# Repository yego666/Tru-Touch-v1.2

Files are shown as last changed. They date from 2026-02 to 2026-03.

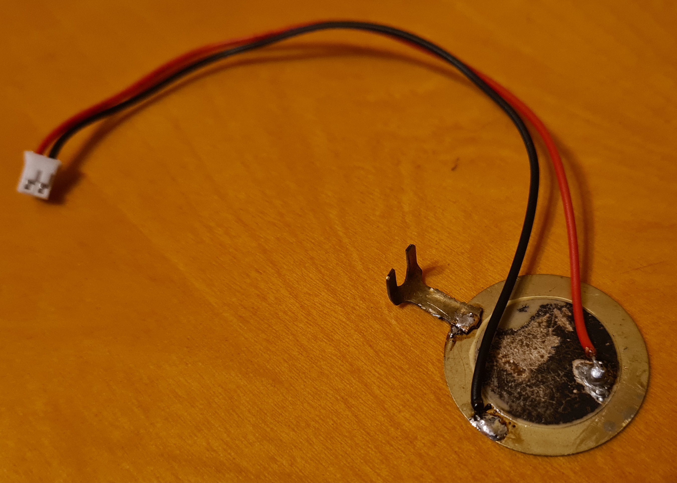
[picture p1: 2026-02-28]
docs/assets/wiring/piezo_sensor.jpg

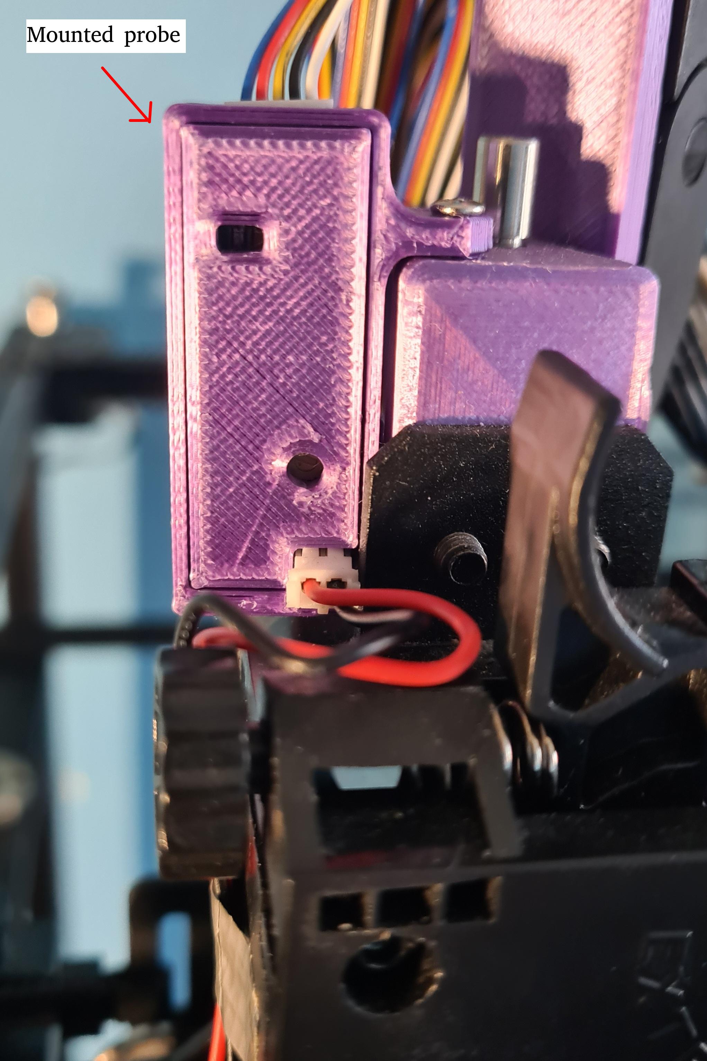
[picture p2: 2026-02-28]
docs/assets/images/mounted-probe.jpg

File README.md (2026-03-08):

# Tru-Touch v1.2 – 1.5-Micron Precision Nozzle-Contact Probe for 3D Printers

# 🚀 Tru-Touch v1.2: High-Precision Nozzle Probe

**Tru-Touch v1.2** is an intelligent, piezoelectric nozzle-contact probe designed for 3D printers.  
It achieves sub-micron precision by using the **nozzle itself** as the trigger point — eliminating offset calibration.

### Key Performance Metrics


- **Precision (Repeatability)**:  1.5 Microns (0.0015 mm) verified
- **Typical Standard Deviation**: 0.001369 mm (validated in Klipper, stats provided)
- **Zero Offset on All Axes**:    Probes directly with the nozzle — no X/Y offset calibration
- **Thermal Stability**:          Controller board detached from piezo sensor
- **No Maintenance Solution**:    Install, Fine-tune, Set up, and forget.
- **Perfect for Adaptive Bed Meshing**: Works perfectly with native Klipper Adaptive Bed Meshing

### Hardware Features
- **One-Screw Mounting**: Minimalist carriage mount; adds negligible mass to the toolhead
- **Easy Installation**:  Reuses existing BL-Touch cabling with minor adjustments
- **Hybrid Processing**:  Analog preconditioning + DSP for superior noise rejection
- **Visual Feedback**:    Dual LEDs with heartbeat and real-time contact-blink patterns
- **User Tunable**:       Onboard potentiometer to match trigger threshold to your gantry resonance

Tru-Touch Probe

 ***Note*** : Battery not included.
### CRITICAL: SIMPLE PLUG RE-PINNING REQUIRED
Tru-Touch v1.2 uses a specialized safety-interlock pin-out. You **MUST** rearrange your JST/DuPont connector to match the TRU-TOUCH row before applying power.

### Repository Contents
- `README.md`: Introduction to the Tru-Touch Probe and its features
- `TruTouch_v1.2_Mechanical.step`: 3D model for designing custom mounts.
- `Physical-Installation.pdf`: Full technical specs and physical installation instructions.
- `Klipper_Integration_Guide.pdf`: Detailed Klipper integration instructions.
- `Probe_Tuning_Guide.pdf`: Step by step guide on probe tuning for best performance
- `Printing_notes.pdf`: Some notes on leveling and printing with the Tru-Touch Probe

Installation Guide: [TruTouch_v1.2_Physical-Installation.pdf](https://github.com/yego666/Tru-Touch-v1.2/blob/main/docs/guides/physical-installation.pdf))

klipper_integration_guide: [TruTouch_v1.2_klipper_integration_guide.pdf](https://github.com/yego666/Tru-Touch-v1.2/blob/main/docs/guides/klipper_integration_guide.pdf))

probe_tuning_guide: [TruTouch_v1.2_probe_tuning_guide.pdf](https://github.com/yego666/Tru-Touch-v1.2/blob/main/docs/guides/probe_tuning_guide.pdf))

printing_notes.: [TruTouch_v1.2_printing_notes.pdf](https://github.com/yego666/Tru-Touch-v1.2/blob/main/docs/guides/printing_notes.pdf))

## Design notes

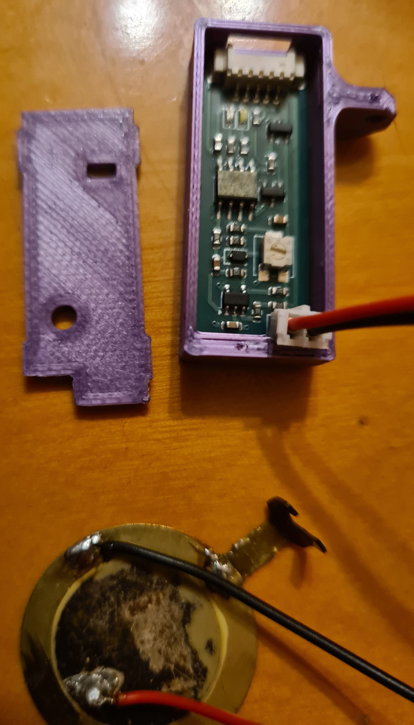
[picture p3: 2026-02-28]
docs/assets/images/trutouch-case.jpg

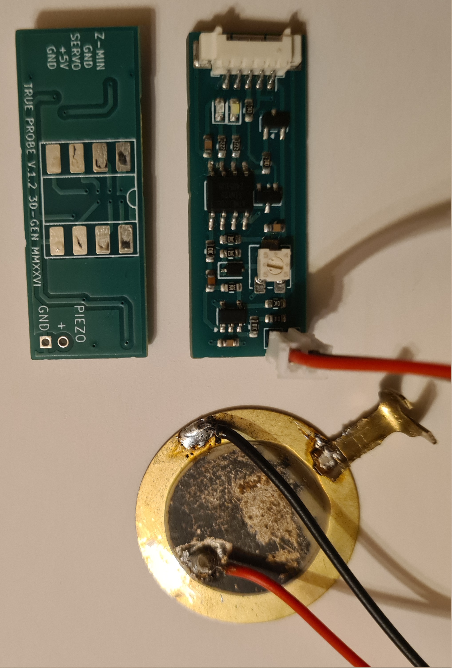
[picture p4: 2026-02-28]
docs/assets/images/trutouch_set.jpg

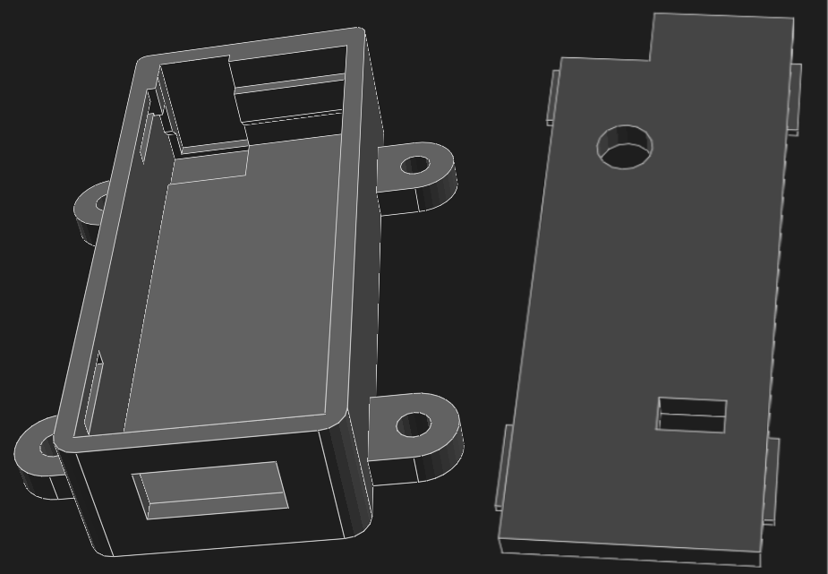
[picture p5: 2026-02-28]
docs/assets/images/trutouch_case.png

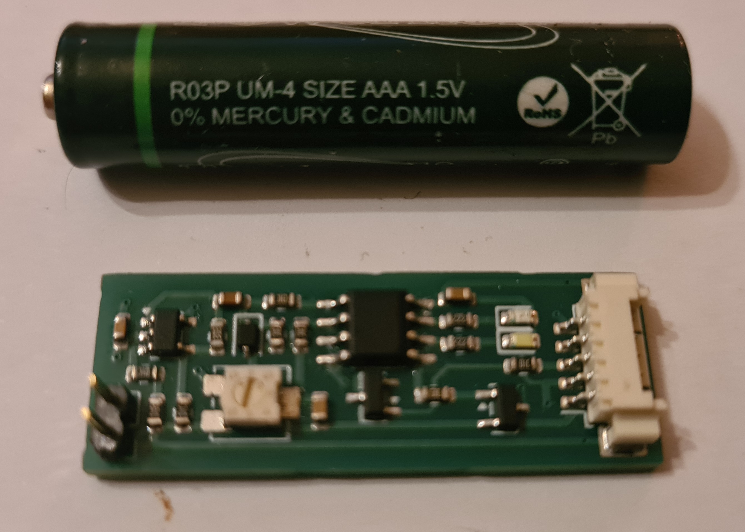
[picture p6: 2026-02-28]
docs/assets/images/trutouch_real-view.jpg

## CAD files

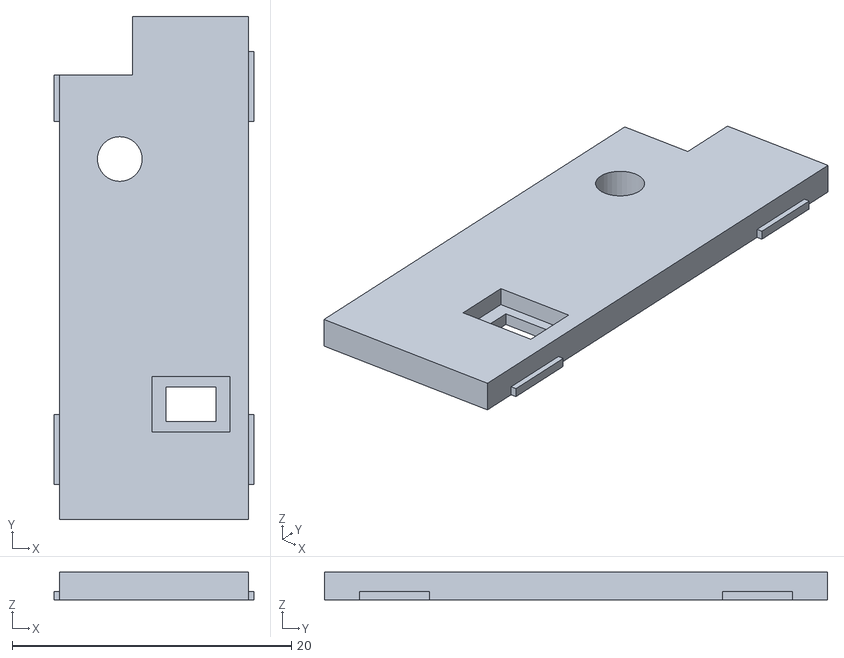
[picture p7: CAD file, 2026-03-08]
docs/stl-step/trutouch-cover.stl
14.3 x 36.0 x 2.00

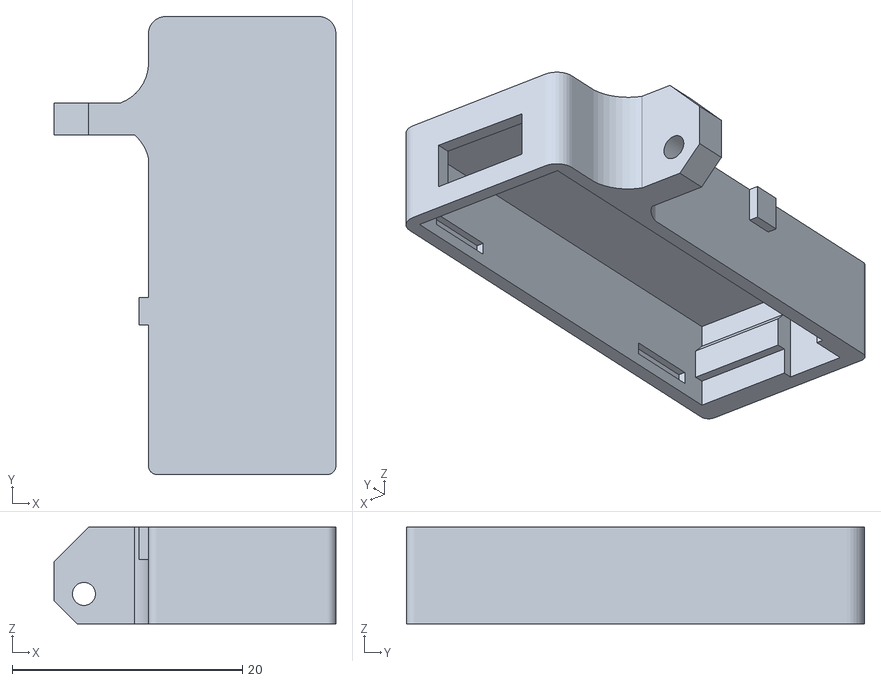
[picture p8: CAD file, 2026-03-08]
docs/stl-step/trutouch-base-2.stl
24.5 x 39.8 x 8.40

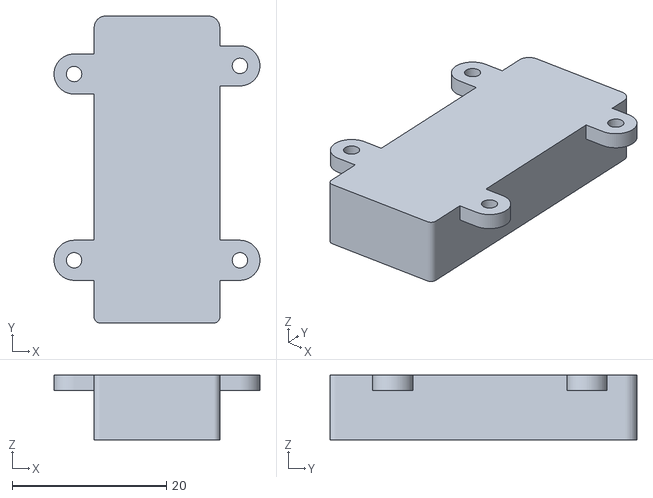
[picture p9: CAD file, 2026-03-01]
docs/stl-step/trutouch-base-1.stl
26.7 x 39.8 x 8.40

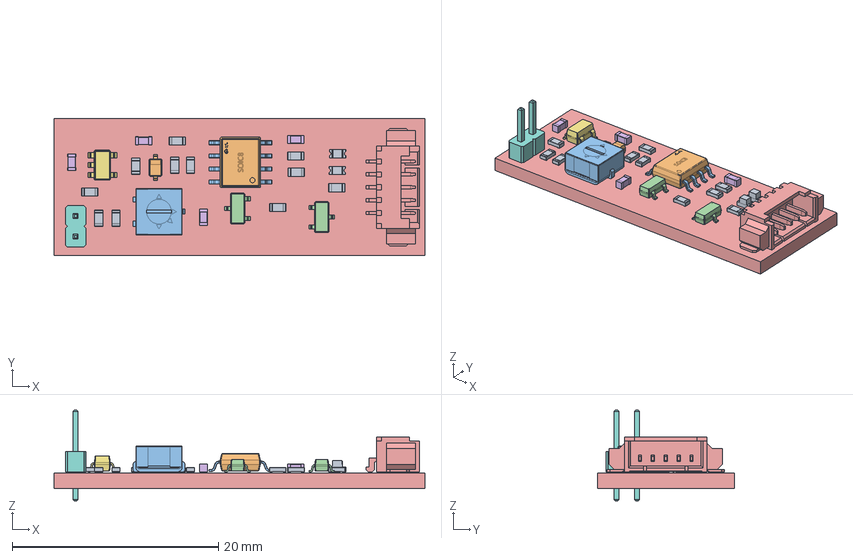
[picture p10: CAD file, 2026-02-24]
docs/stl-step/trutouch.step
35.9 x 13.3 x 8.80 mm
R_0603
D_SOD-323
R_0603_1608Metric x 10
Potentiometer_Bourns_3314J_Vertical
SOT-23 x 2
Molex_PicoBlade_53261-0571_1x05-1MP_P1.25mm_Horizontal
C_0603 x 4
SOT-23-5
PinHeader_1x02_P2.00mm_Vertical
D_0603 x 2
SOIC-8_L4.9-W3.9-P1.27-LS6.0-BL
jlcpcb_probe-v1.2_PCB

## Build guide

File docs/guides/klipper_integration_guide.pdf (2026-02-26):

Having completed all the steps in the Physical Installation Guide successfully, you can now integrate your new Tru-Touch piezo probe into your Klipper configuration so you can start using it. Basic (and most crucial) configuration takes place in the printer.cfg file, where all hardware features must be clearly specified.
With proper (re-)wiring, the two most important signals are covered: Z-MIN feedback signal, and the SERVO probe control signal.

# Configuration Options: BLTouch Mode vs. Simple Probe Mode

Tru-Touch may be configured either as a direct BLTouch/CR-Touch replacement from the signaling perspective, or as a probe with the simple ON/OFF control signal.
Depending on the way it is configured in the printer.cfg file, the probe will automatically switch to the chosen mode.
Both modes have their pros and cons.
Choosing the BLTouch compatible mode you are bound to tight PWM timing/control signals, which may be misinterpreted in some printers due to noise, timing jitter, or board-specific quirks. This could cause misinterpretation of deploy/stow commands, potentially leading to bed crashes, false triggers, or no triggers at all.

# The Tru-Touch probe emulates only the basic BLTouch commands, as the Touch Mode Fast

scanning mode cannot be safely implemented with piezo sensors.
However, BLTouch mode allows for an almost plug-and-play configuration if you already have a BLTouch defined in printer.cfg.
The Simple Probe Mode offers a very simple and straightforward configuration, while giving you full control over probing speed and various other probing parameters.
It uses the same wiring and control signals as the BLTouch mode, so no printer board rewiring is required. BLTouch probe control signals may be safely reused.
This mode is also slightly faster than the BLTouch mode as Klipper must take care of just ON and OFF states instead of handling more complicated PWM control signal sequences.
The following sections explain both modes in detail, including recommended printer.cfg entries and tuning tips for optimal piezo performance.

BLTouch Mode

[bltouch]

sensor_pin: your sensor (Z-MIN) pin designator | # for instance PF12
control_pin: your control (servo) pin designator | # for instance PB10
pin_move_time: 0.020 | # must be set low to avoid conflict with Tru-Touch timing
stow_on_each_sample: True | # must be set True for proper Tru-Touch operation
probe_with_touch_mode: False | # no Touch Mode is available
x_offset: 0 | # this offset must be set to “0” as the nozzle is your probe
y_offset: 0 | # this offset must be set to “0” as the nozzle is your probe
z_offset: 0 | # this offset must be set to “0” as the nozzle is your probe
speed: 6.7 | # adjust within safe limits [5, 7] mm/s

lift_speed: 30

sample_retract_dist: 4 | # set it the same as the [stepper_z]:homing_retract_dist
#samples: 3 | # the number of samples to take at the same x/y spot

#samples_result: median | # samples beyond the samples_tolerance will be discarded

#samples_tolerance: 0.010 | #samples_tolerance_retries: 3

Simple Probe Mode:

[probe]

pin: your sensor (Z-MIN) pin designator | # for instance PF12
x_offset: 0 | # this offset must be set to “0” as the nozzle is your probe
y_offset: 0 | # this offset must be set to “0” as the nozzle is your probe
z_offset: 0 | # this offset must be set to “0” as the nozzle is your probe
speed: 6.7 | # adjust within safe limits [5, 7] mm/s
sample_retract_dist: 4 | # set it equal to [stepper_z]:homing_retract_dist
#samples: 3 | # the number of samples to take at the same x/y spot

#samples_result: median | # samples beyond the samples_tolerance will be discarded

#samples_tolerance: 0.010

#samples_tolerance_retries: 3

activate_gcode:

PROBE_ON

deactivate_gcode:

PROBE_OFF

#--------- Control Pin Macro for the Simple Probe Mode ----------

[output_pin servo_pin]

pin: your control (servo) pin designator | # for instance PB10

pwm: False

value: 0

[gcode_macro PROBE_DEPLOY]

gcode:

SET_PIN PIN=servo_pin VALUE=0

[gcode_macro PROBE_STOW]

gcode:

SET_PIN PIN=servo_pin VALUE=1

Settings common to both modes:

[stepper_z]

position_min: -1.0 | # too low value may cause no trigger error,

# due to motion planner limitations

homing_speed: 6.7

homing_retract_dist: 4 | # Distance to back off after first and second homing
second_homing_speed: 6.7 | # should be given the same value as the homing_speed

[safe_z_home]

z_hop: 4 | # Distance (in mm) to lower the bed prior to first homing.

# Best to set it the same as the [stepper_z]:homing_retract_dist

[bed_mesh]

horizontal_move_z: 4 | # The height (in mm) that the bed should move to,
| # just prior to starting a mesh probe operation.
| # Set it the same as the [stepper_z]:homing_retract_dist
#-⁻ | Extra macros needed for easy Tru-Touch probe setup for both modes -⁻

# Use the UNLOCK_Z macro to move the bed up or down if G28 fails to home the Z AXIS

[force_move] | # This block is required by the SET_KINEMATIC_POSITION
| # commands in the UNLOCK_Z macro below

enable_force_move: True

[gcode_macro UNLOCK_Z]

gcode: SET_KINEMATIC_POSITION Z=100

Note: Only parameters directly impacting the Tru-Touch probe’s operation have been displayed above. Other parameters may be left unmodified as they were before if they don’t collide with settings discussed above.
If the parameter “z_offset” is present in the SAVE_CONFIG section, remove it as it will override, thus invalidate your “0” offset settings.

# The [bltouch] and the [probe] sections cannot be defined at the same time within the same

printer.cfg file, as that will cause configuration conflict.

Whichever mode you choose, you may switch to the other at any time, as once properly (re-)wired, your probe is electrically identical for both modes, hence the same pins are used in both cases.

Hence the power up sequence has been covered in the installation Guide, we may proceed to the Probe Tuning Guide.

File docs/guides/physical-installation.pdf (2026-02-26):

## Tru-Touch v1.2 Wiring Diagram – 1.25 mm Picoblade Connector CRITICAL SAFETY WARNING – READ BEFORE CONNECTING POWER

Re-pin the printer-side female plug to match the colors and functions shown below. Incorrect wiring order WILL DAMAGE the probe and/or printer electronics.

Always verify with a multimeter before first power-up.

Two GND wires (red and white) — connect both to the printer board’s GND (signal & power noise reduction).

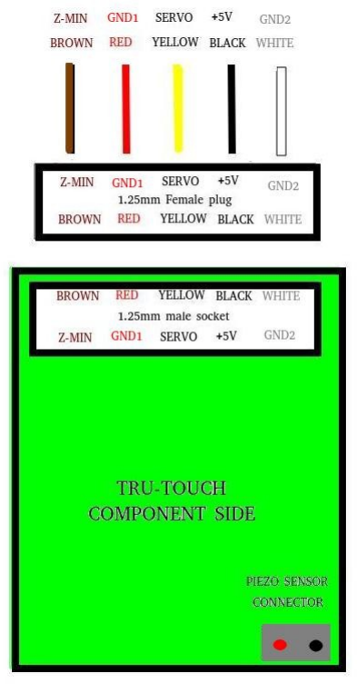
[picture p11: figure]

## Viewed from Component Side & Quick Reference – Wire Matching

(green PCB facing you, with the connector also on the component side).

⁻ | Brown | → | Z-MIN (probe trigger output to Klipper sensor_pin)
⁻ | Red | → | GND1
⁻ | Yellow | → | SERVO (PWM command from Klipper)
⁻ | Black | → | +5V (power from printer)
⁻ | White | → | GND2

## Piezo Sensor

The piezo sensor is a small disc with a diameter of roughly 30 mm.

It consists of a brass base (yellow, metallic part) and a piezo-ceramic sensor located centrally on the brass base.

There are two wires soldered to the component.

The red one is soldered to the piezo-ceramic disc, while the black one is soldered to the brass rim. Those wires are crimped into the 2 mm female plug, which should be plugged into the Piezo Sensor Connector on your Probe as discussed below.

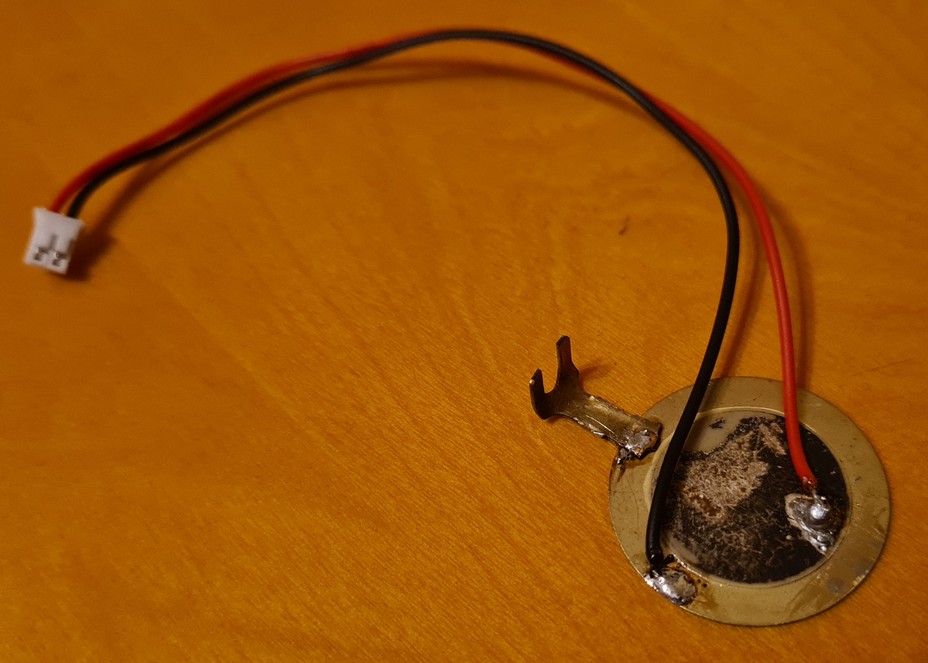
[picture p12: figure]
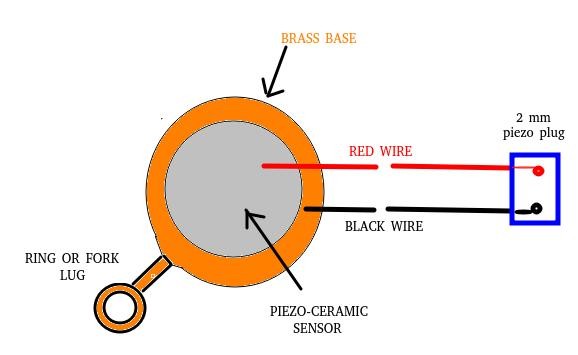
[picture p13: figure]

You can see the Fork Lug (left picture), and the Ring Lug (right picture) soldered to the brass rim of the disc. This lug is used to attach the whole piezo assembly to your printer’s carriage.

It must be attached with a suitable screw to allow it to receive the vibrations from the nozzle tapping against your printer’s bed.

## Best place to attach your piezo assembly:

1. The piezo disc must be fixed parallel to the printer’s bed.
2. It must be attached to the same back-plate that the hot-end is attached to,
3. For best performance it should be not closer to the bed than 45 – 50 mm,
4. It must be attached firmly to let the vibration easily pass from the nozzle.

## Piezo Sensor Connector (bottom right on PCB)

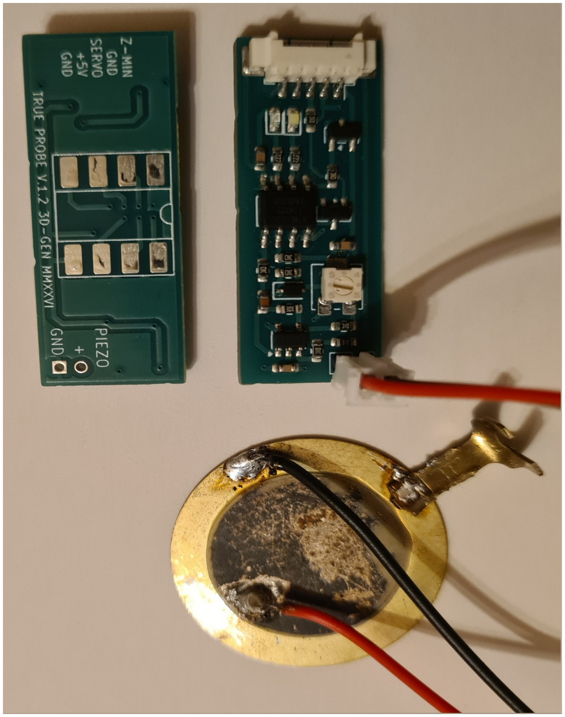
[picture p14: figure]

Connect the piezo disc:

red wire to the marked (+) pin,

black wire to the marked (GND) pin.
Polarity matters: The brass part of the piezo disc connects to the printer’s ground via the frame.

Note: Ensure the nozzle and the bed are clean and debris-free for reliable performance.

## First Power-Up Check

After wiring:

1. Power on the printer → the RED LED and the WHITE LED should blink quickly several times (self-test state), and eventually rest with the RED LED OFF and the WHITE LED dimmed.
2. Send the “BLTOUCH_DEBUG COMMAND=pin_down” → the heartbeat LED (white) dims, then turns ON.
3. Manually trigger piezo → the contact LED (red) turns on, and remains triggered (ON) until the “BLTOUCH_DEBUG COMMAND=pin_up” is received.

If no LEDs light up or if there is wrong behavior → re-check the wiring & re-pin the connector.

When all steps have been passed successfully, you may proceed to the Klipper Integration Guide.

## Tools needed:

Multimeter, small flat or philips screwdriver, caliper for verification, sharp needle or a pin for signal connector re-pinning.

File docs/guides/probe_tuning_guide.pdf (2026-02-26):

### Probe Tuning Guide

Assuming that your printer is connected to the controlling computer, and Klipper is configured according to the guidelines in the Klipper Integration Guide, you should be able to command your printer via your favorite interface.

First of all — for your printer’s safety — turn off the printer and manually move your bed away from the nozzle to give it some slack to move toward the bed without hitting it. A 100 mm distance is recommended for a large error margin.

Now you may turn your printer back on and wait for it to boot up completely so you can access the Klipper console from your computer.

First, we need to set the rough sensitivity threshold for the probe.
Important note: The potentiometer is rather tiny, so changes to the probe’s sensitivity must be executed with a tiny flat screwdriver using just minute adjustments, as less precise adjustments may cause huge sensitivity changes.

### BLTouch Mode

Run the BLTOUCH_DEBUG COMMAND=pin_down. This command activates your probe — analogous to the Deploy command in a classic BLTouch probe.

The LED pattern on the probe will change as follows: RED LED turns OFF, White LED turns OFF for half a second and then turns ON, signaling the deployment sequence is complete.

[1C] Now the probe is awaiting the tap on the nozzle.

Take a screwdriver or even a steel spoon and very gently tap the bottom of the nozzle.

If the RED LED remains dim after the tap, turn the potentiometer located on the probe's PCB counterclockwise very slightly to increase the piezo sensor sensitivity, and repeat the procedure from point [1C] until the RED LED lights up.

If the RED LED lights up, send the BLTOUCH_DEBUG COMMAND=pin_up command to the printer.

The probe should return to idle state, reporting its state with the RED LED off and the WHITE LED dim.

### Simple Probe Mode

Run the PROBE_DEPLOY macro. This command activates your probe.

The LED pattern on the probe will change as follows: RED LED turns OFF, White LED turns OFF for half a second and then turns ON, signaling the deployment sequence is complete.

[1T] Now the probe is awaiting the tap on the nozzle.

Take a screwdriver or even a steel spoon and very gently tap the bottom of the nozzle.

If the RED LED remains dim after the tap, turn the potentiometer located on the probe's PCB counterclockwise very slightly to increase the piezo sensor sensitivity, and repeat the procedure from [1T] until the RED LED lights up.

If the RED LED lights up, run the PROBE_STOW macro.

The probe should return to idle state, reporting its state with the RED LED off and the WHITE LED dim.

### Common

Now the probe knows roughly the trip point.

To fine-tune this trip point, run the UNLOCK_Z macro, which will let you move your printhead over all axes.

Move your printhead to the center of your printer’s bed with the G0 X100 Y100 F5000 command (or similar depending on your bed size). This spot is usually the most suitable place to fine-tune your probe.

Once the printhead is above the bed center:

### BLTouch Mode

[2B] Run the BLTOUCH_DEBUG COMMAND=pin_down command.

Move the bed closer to the nozzle with the G0 Z90 F402 command (speed: 6.7 mm/s * 60 = 402 mm/min), while watching the RED LED on the Tru-Touch probe.

If it lights up, the sensor is too sensitive, so turn the potentiometer very slightly clockwise to lower this sensitivity. Next, run the BLTOUCH_DEBUG COMMAND=pin_up command to stow the probe, move the bed back to its initial position with the G0 Z100 F402 command, and return to step [2B].

### Simple Probe Mode

[2S] Run the PROBE_DEPLOY macro.

Move the bed closer to the nozzle with the G0 Z90 F402 command (speed: 6.7 mm/s * 60 = 402 mm/min), while watching the RED LED on the Tru-Touch probe.

If it lights up, the sensor is too sensitive, so turn the potentiometer very slightly clockwise to lower this sensitivity. Next, run the PROBE_STOW macro to stow the probe, move the bed back to its initial position with the G0 Z100 F402 command, and return to step [2S].

### Common

If the RED LED stays off, the sensor’s sensitivity may be close to optimal.

To make sure that your tuning is correct, you may rerun the tuning procedure several times.

Once you are done with fine-tuning your probe, the real HOME cycle must be done.

While your bed is still well away from the nozzle, grab the screwdriver or a spoon or whatever hard tool you used to tap the nozzle and run the G28 command to home all three axes of your printer.

First your printer will home the X and Y axes. Next it will go to the spot marked [safe_z_home]:home_xy_position: 156,156.

Once this spot is reached, the probe will deploy (watch LEDs), and the probing cycle will begin.

After the bed has traveled half the distance to the nozzle (or vice versa), gently tap the nozzle with a tool at hand. The second homing cycle will start. Again tap gently the nozzle to end the cycle. If the probe failed to detect your taps, turn off your printer to avoid any damage. In this case, the tuning procedure must be carried on again with greater care.

If, however, the probe detected your gentle taps, you may re-run the G28 command without tapping the nozzle before it reached the bed. Nevertheless, be prepared to cut your printer’s power in case the probe failed to detect the tap. In such unlikely case, the tuning procedure must be carried on again with greater care.

When your printer has been homed successfully, you should run the first surface scan (leveling) to fine-fine tune your probe.

The scan boundaries are defined in the printer.cfg file as [bed_mesh]:mesh_min: 30,30, and [bed_mesh]:mesh_max: 282,282.

Note that your bed may be much noisier on its outer rim, therefore use conservative boundaries for your first surface scan.

Later on those boundaries may be extended to your whole bed area.

### Bed Leveling

[3L] Run the BED_MESH_CALIBRATE command from your console. Best start with [bed_mesh]:probe_count: 3,3 to save time in case of failure.

If at any mesh point your probe triggers prematurely, you’ll need to slightly lower the probe’s sensitivity and start over at point [3L].

If, however, the probe missed the tap, the sensitivity must be increased slightly with the potentiometer. Rerun the Bed Leveling procedure from [3L] once you trimmed the sensitivity. Note: Missed tap may also result from the nozzle or bed not being clean enough.

Once the leveling was successful, you may rerun it with [bed_mesh]:probe_count: set to your desired values.

Note !!!: The potentiometer is not your only tool to fight over or under sensitivity.

In unlikely case where you get both premature triggers and missed taps, you may tune the noise with the “speed” parameters both in [bltouch] or [probe] sections, and [stepper_z] section.

While changing the “speed” parameter value keep in mind that the probe is literally “deaf” while the WHITE LED is OFF.

It gets armed when the WHITE LED turns fully ON, which takes place about half a second after the “BLTOUCH_DEBUG COMMAND=pin_down”|“PROBE_DEPLOY” command has been received by the probe.

This measure has been built in to follow the BLTouch behavior.

For instance, when you set the “speed” parameters to 7 mm/s, your probe will be active for the last 0.5 mm above the bed.

This in turn means that setting the [stepper_z]:homing_retract_dist: 4, or [safe_z_home]:z_hop: 4, or [bltouch|probe]:sample_retract_dist: 4, may not be sufficient for safe probing distance margin.

So consider increasing those parameters while raising the “speed” parameter value to allow your probe to “arm” before hitting the bed.

Conversely, the distance parameters may be decreased when you lower the value of the “speed” parameters.

If you have successfully completed the whole probe installation and integration, please read the Printing_Notes file, where there are some guidelines and configuration examples gathered by the author over the year of using the Tru-Touch Probe.
